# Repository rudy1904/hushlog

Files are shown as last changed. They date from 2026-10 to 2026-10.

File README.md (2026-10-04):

# Hushlog

A 4-channel, 24-bit data logger for small, slow signals — thermocouples, strain gauges, photodiodes, RTDs.

Most DIY loggers read tiny voltages with the microcontroller's built-in ADC, which is fine until the signal is small, at which point it's mostly noise. Hushlog uses a real 24-bit precision ADC (the TI ADS1220) with 4 input channels, read by a bare RP2040, logged to a microSD card, with a small OLED for live readings — all on a custom 2-layer board in a 3D-printed enclosure.

The thing I actually care about is keeping it **quiet**: a separate low-noise supply for the analog side, RC filtering on every input, and a layout that keeps the digital switching noise away from the ADC. Once it's built I'll short the inputs, measure the noise floor, and compare it to the datasheet — that number goes in this repo, good or bad.

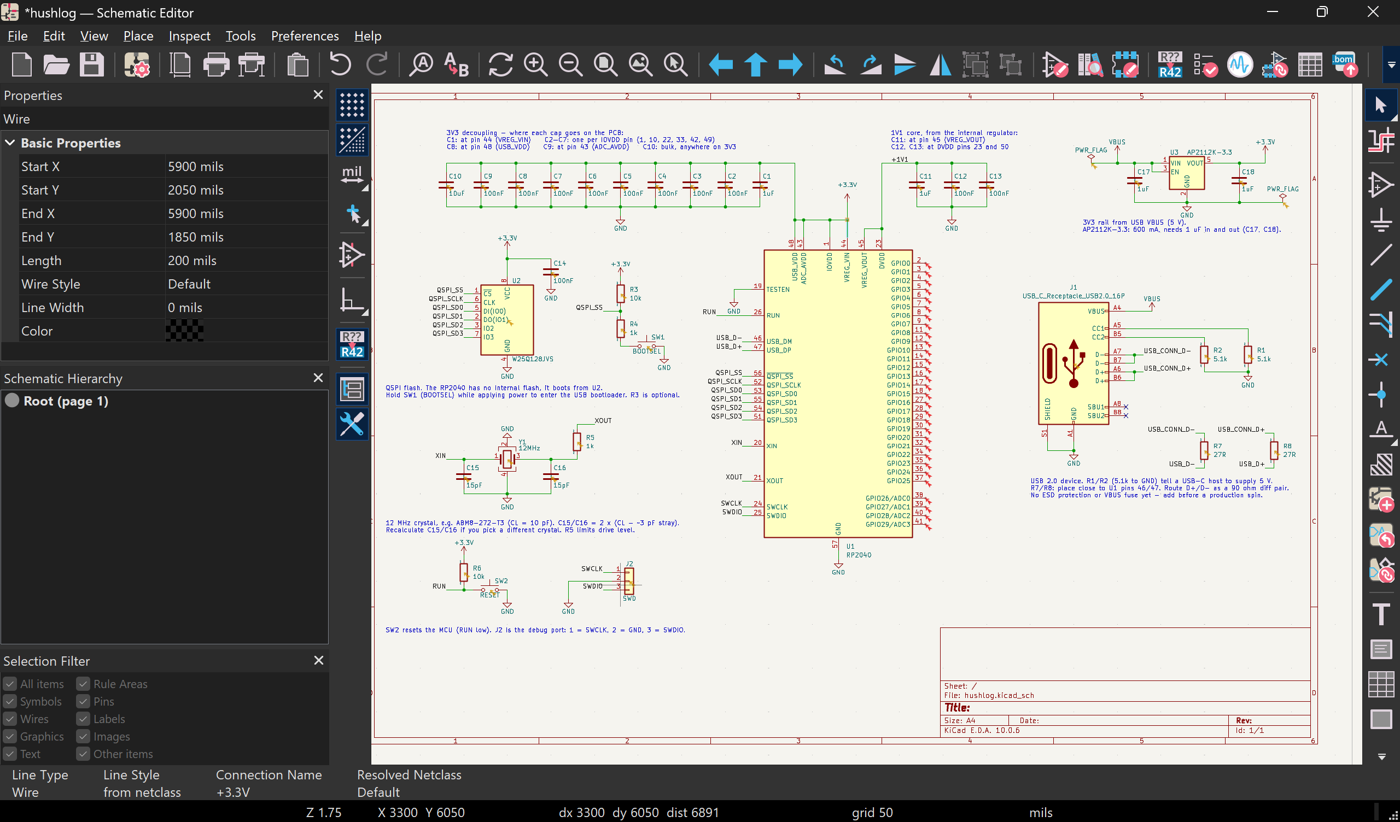
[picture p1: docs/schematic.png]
RP2040 core schematic


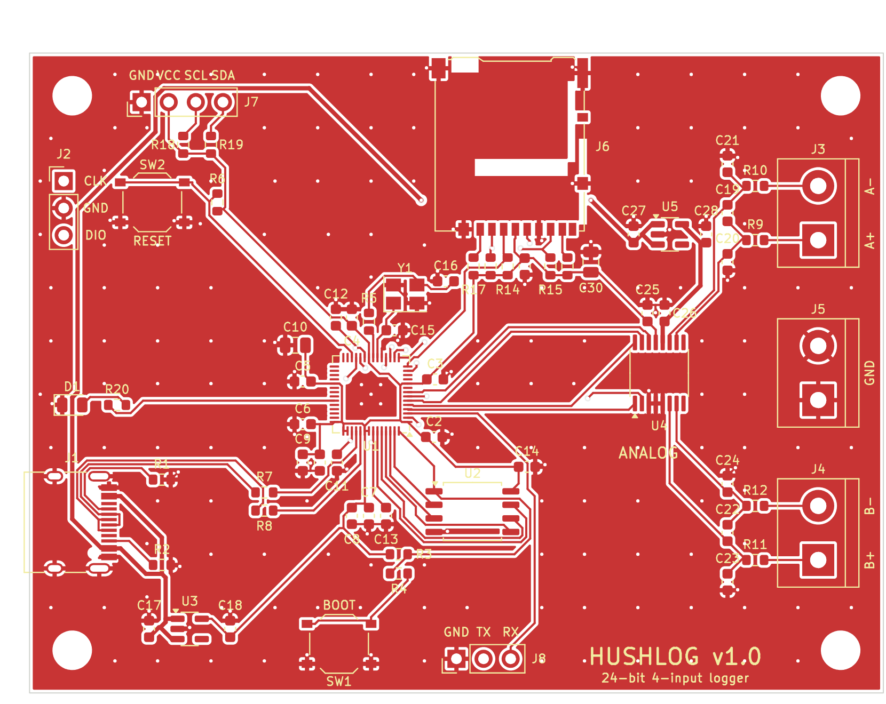
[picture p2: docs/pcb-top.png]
PCB, top copper and silkscreen


## Status

Design in progress for the Hack Club Half Life warm-up (Tier 2).

- [x] RP2040 core schematic — MCU, external QSPI flash, 12 MHz crystal, USB-C + LDO power, BOOTSEL/RESET, SWD. Power rails verified (VREG_VIN confirmed on +3.3V).
- [x] ADS1220 analog front end — two differential channels, computed input filters, SPI on hardware SPI0, separate low-noise LDO (AVDD isolated from digital rail, verified)
- [x] microSD (SPI1), OLED header (I2C1), screw terminals, status LED, UART header
- [x] PCB layout — 80 × 60 mm, 2 layers, analog/digital split, ground pour on both sides. Passes DRC with 0 errors and 0 unrouted nets in KiCad 7's DRC engine; still to be re-checked in KiCad 10 before ordering.
- [ ] Enclosure (3D-printed)
- [ ] Firmware (RP2040 + ADS1220 + SD logging)

## Design choices

- **Bare RP2040, not a Pico module** — designing the MCU circuit from scratch (reference design followed pin-for-pin so it boots first try).
- **External QSPI flash (W25Q128)** — the RP2040 has no internal flash.
- **Separate analog supply** — the ADC gets its own low-noise LDO so RP2040 switching noise doesn't couple into the measurement.
- **2-layer board** — kept deliberately simple for a first build; no need for 4 layers at these speeds.

## PCB

- 80 × 60 mm, 2 layers, four M3 mounting holes. Minimum track and gap 0.2 / 0.15 mm, vias 0.6 / 0.3 mm.
- Digital on the left (RP2040, flash, USB-C, microSD, OLED header), analog on the right (ADS1220, input filters, screw terminals, analog LDO).
- The bottom layer under the analog section is unbroken ground: a rule area forbids bottom-layer tracks there, so nothing can cut the plane under the ADC or the input filters.
- The 5 V feed for the analog LDO runs around the board edge and passes under the microSD socket, where no signal crosses the gap it leaves in the plane. It never enters the input-filter area.
- Input pairs: J3 = IN_A (pin 1 AIN1, pin 2 AIN0), J4 = IN_B (pin 1 AIN3, pin 2 AIN2), J5 = ground. MUX settings 0110 and 0111 make pin 1 the positive input.
- Fabrication files are in `fab/` (Gerbers, drill, placement, parts list).

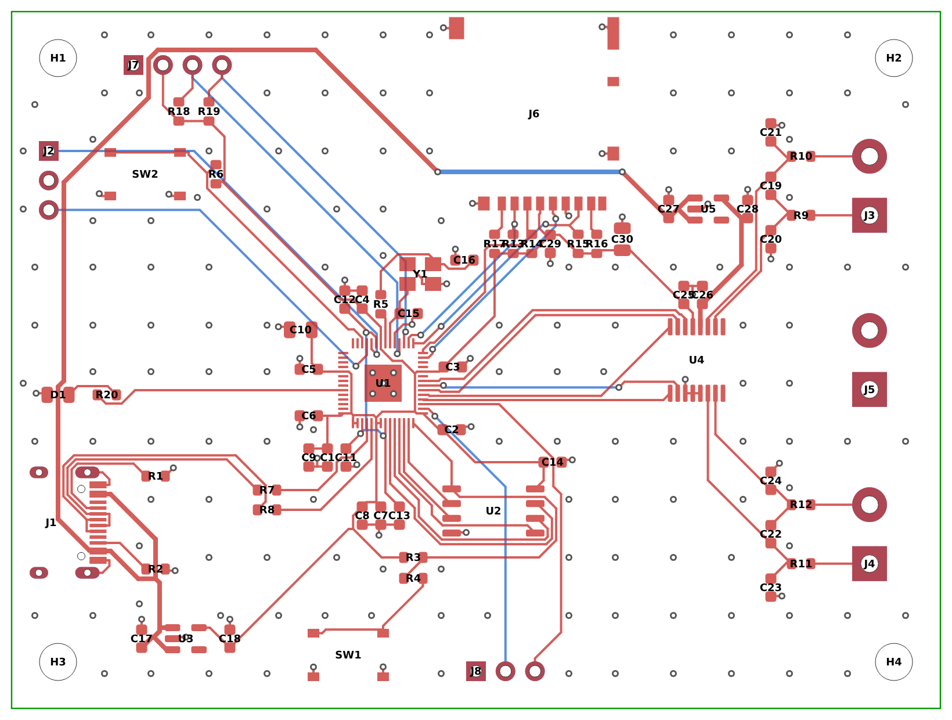
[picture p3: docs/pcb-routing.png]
PCB routing, both layers


## Hardware

- `hardware/` — KiCad 10 project (schematic + PCB)
- `docs/` — schematic render, board images, noise-floor results
- `cad/` — enclosure files
- `firmware/` — RP2040 firmware

## Parts (headline)

| Part | Role |
|---|---|
| RP2040 | microcontroller |
| W25Q128 | QSPI boot flash |
| ADS1220 | 24-bit ADC (4 ch) |
| AP2112K-3.3 | 3.3V LDO (digital) |
| TPS7A20 | low-noise LDO (analog) |
| SSD1306 0.96" | OLED display |

Full bill of materials in `BOM.md` (auto-synced from the Half Life project).

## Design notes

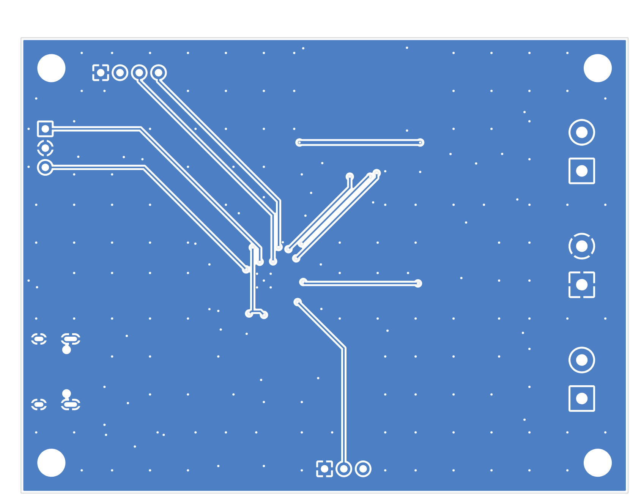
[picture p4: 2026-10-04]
docs/pcb-bottom.png

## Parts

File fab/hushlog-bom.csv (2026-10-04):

References | Qty | Value | Footprint | Part | Manufacturer | LCSC (unverified) | Unit price | Notes
C1 C11 C17 C18 C27 C28 | 6 | 1uF | C_0603_1608Metric | 1uF 0603 capacitor |  |  |  | X7R, 10 V or more (C17/C27 sit on 5 V VBUS)
C2 C3 C4 C5 C6 C7 C8 C9 C12 C13 C14 C19 C22 C25 C26 C29 | 16 | 100nF | C_0603_1608Metric | 100nF 0603 capacitor |  |  |  | X7R; C19/C22 (across the input pairs) are better as C0G/NP0 or film if the budget allows
C10 C30 | 2 | 10uF | C_0805_2012Metric | 10uF 0805 capacitor |  |  |  | X5R/X7R, 10 V or more
C15 C16 | 2 | 15pF | C_0603_1608Metric | 15pF 0603 capacitor |  |  |  | crystal load: C0G/NP0
C20 C21 C23 C24 | 4 | 10nF | C_0603_1608Metric | 10nF 0603 capacitor |  |  |  | input common-mode filter: use C0G/NP0
D1 | 1 | LED | LED_0805_2012Metric | 0805 green LED
J1 | 1 | USB_C_Receptacle_USB2.0_16P | USB_C_Receptacle_HRO_TYPE-C-31-M-12 | TYPE-C-31-M-12 | Korean Hroparts | C165948 |  | 16-pin USB 2.0 receptacle
J2 | 1 | SWD | PinHeader_1x03_P2.54mm_Vertical | 1x3 2.54 mm header
J3 | 1 | IN_A | TerminalBlock_bornier-2_P5.08mm | 2-way 5.08 mm screw terminal
J4 | 1 | IN_B | TerminalBlock_bornier-2_P5.08mm | 2-way 5.08 mm screw terminal
J5 | 1 | GND | TerminalBlock_bornier-2_P5.08mm | 2-way 5.08 mm screw terminal
J6 | 1 | Micro_SD_Card | microSD_HC_Hirose_DM3AT-SF-PEJM5 | DM3AT-SF-PEJM5 | Hirose | C114218 |  | push-push; footprint is for this exact part
J7 | 1 | OLED | PinHeader_1x04_P2.54mm_Vertical | 1x4 2.54 mm header (or socket) |  |  |  | for a 0.96 in SSD1306 I2C module, pin order GND-VCC-SCL-SDA
J8 | 1 | UART | PinHeader_1x03_P2.54mm_Vertical | 1x3 2.54 mm header
R1 R2 | 2 | 5.1k | R_0603_1608Metric | 5.1k 0603 resistor 1%
R3 R6 R13 R14 R15 R16 R17 | 7 | 10k | R_0603_1608Metric | 10k 0603 resistor 1%
R4 R5 R9 R10 R11 R12 R20 | 7 | 1k | R_0603_1608Metric | 1k 0603 resistor 1%
R7 R8 | 2 | 27R | R_0603_1608Metric | 27R 0603 resistor 1%
R18 R19 | 2 | 4.7k | R_0603_1608Metric | 4.7k 0603 resistor 1%
SW1 | 1 | BOOTSEL | SW_Push_1P1T_XKB_TS-1187A | TS-1187A-B-A-B | XKB | C318884 |  | tactile switch 5.1x5.1 mm
SW2 | 1 | RESET | SW_Push_1P1T_XKB_TS-1187A | TS-1187A-B-A-B | XKB | C318884 |  | tactile switch 5.1x5.1 mm
U1 | 1 | RP2040 | QFN-56-1EP_7x7mm_P0.4mm_EP3.2x3.2mm | RP2040 | Raspberry Pi | C2040
U2 | 1 | W25Q128JVS | SOIC-8_5.3x5.3mm_P1.27mm | W25Q128JVSIQ | Winbond | C97521 |  | SOIC-8 208 mil
U3 | 1 | AP2112K-3.3 | SOT-23-5 | AP2112K-3.3TRG1 | Diodes Inc. | C51118
U4 | 1 | ADS1220IPW | TSSOP-16_4.4x5mm_P0.65mm | ADS1220IPWR | Texas Instruments |  |  | TSSOP-16
U5 | 1 | TPS7A2033PDBV | SOT-23-5 | TPS7A2033PDBVR | Texas Instruments |  |  | 3.3 V low-noise LDO
Y1 | 1 | 12MHz | Crystal_SMD_Abracon_ABM8G-4Pin_3.2x2.5mm | ABM8-272-T3 | Abracon |  |  | 12 MHz, CL 10 pF, 3.2x2.5 mm; recalculate C15/C16 for any other crystal
(not on the board) | 1 | OLED module |  | 0.96 in SSD1306 I2C module |  |  |  | check its pin order against J7
(not on the board) | 1 | PCB |  | 80 x 60 mm, 2 layers, 1.6 mm

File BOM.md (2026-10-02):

# Hushlog — bill of materials

<!-- Generated by Half Life from project cmupluruv071a01s14q1s25uq. Edits here are overwritten on the next sync. -->
<!-- Generated: 1970-01-01T00:00:00.000Z -->

> [!NOTE]
> This parts list is mirrored from [Half Life](https://halflife.hackclub.com). Editing it here will not change the platform's copy, and the next sync overwrites this file.

| Week | Tier | Parts funding |
| --- | --- | --- |
| Warm-up | Tier 2 | $65.00 |

_No parts listed yet._

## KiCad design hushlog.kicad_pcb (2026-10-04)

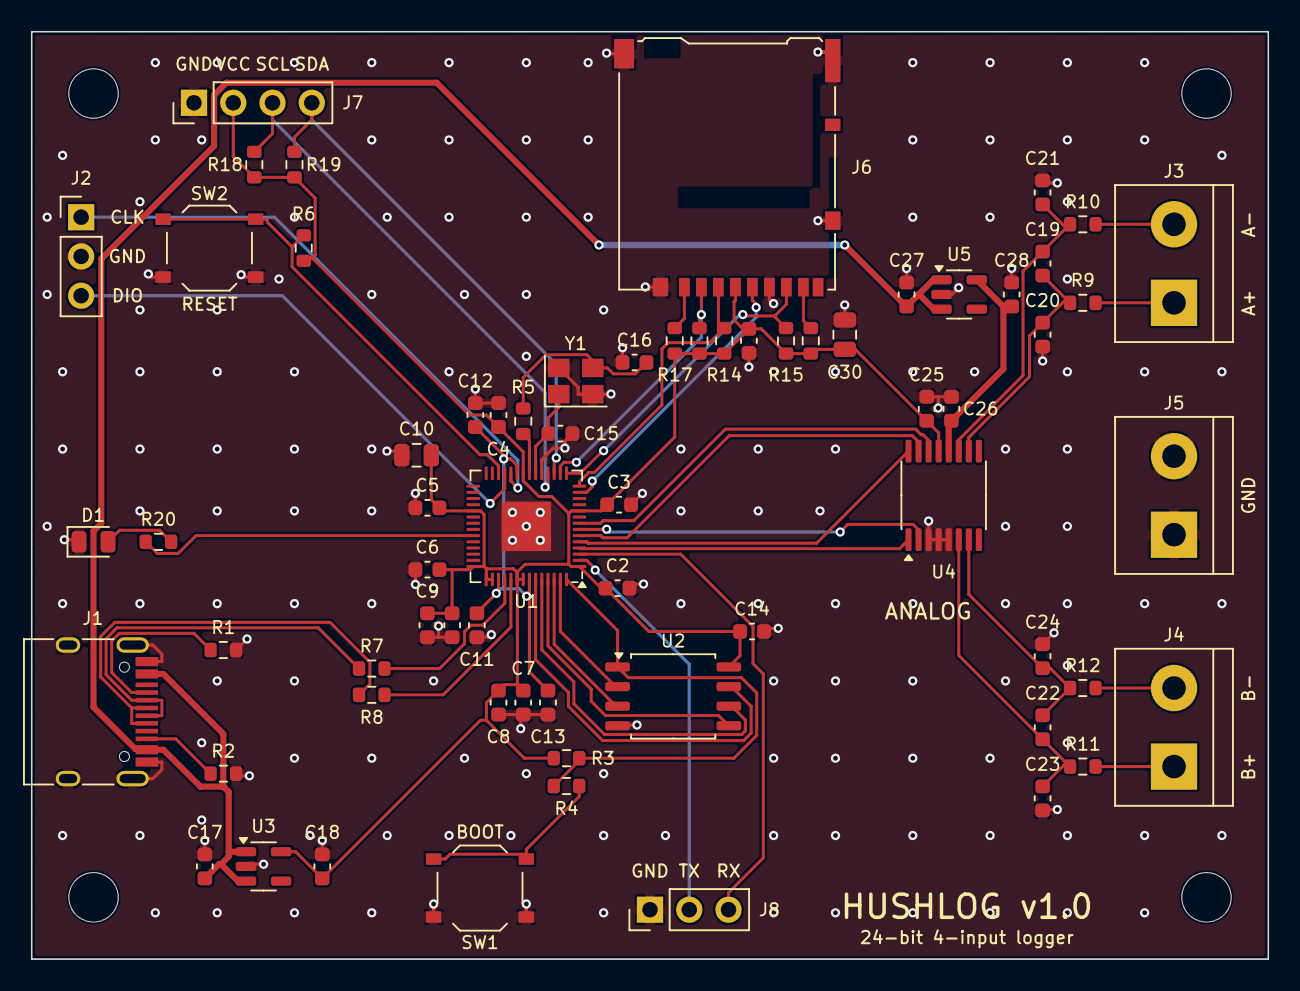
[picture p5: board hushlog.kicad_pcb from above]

Board: 2 copper layers, 80.0 x 60.0 mm, 71 parts (0 on the bottom side), 49 nets.

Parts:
C1, C11, C17, C18, C27, C28: 1uF; C_0603_1608Metric
C2, C3, C4, C5, C6, C7, C8, C9, C12, C13, C14, C19, C22, C25, C26, C29: 100nF; C_0603_1608Metric
C10, C30: 10uF; C_0805_2012Metric
C15, C16: 15pF; C_0603_1608Metric
C20, C21, C23, C24: 10nF; C_0603_1608Metric
D1: LED; LED_0805_2012Metric
H1, H2, H3, H4: M3; MountingHole_3.2mm_M3
J1: USB_C_Receptacle_USB2.0_16P; USB_C_Receptacle_HRO_TYPE-C-31-M-12
J2: SWD; PinHeader_1x03_P2.54mm_Vertical
J3: IN_A; TerminalBlock_bornier-2_P5.08mm
J4: IN_B; TerminalBlock_bornier-2_P5.08mm
J5: GND; TerminalBlock_bornier-2_P5.08mm
J6: Micro_SD_Card; microSD_HC_Hirose_DM3AT-SF-PEJM5
J7: OLED; PinHeader_1x04_P2.54mm_Vertical
J8: UART; PinHeader_1x03_P2.54mm_Vertical
R1, R2: 5.1k; R_0603_1608Metric
R3, R6, R13, R14, R15, R16, R17: 10k; R_0603_1608Metric
R4, R5, R9, R10, R11, R12, R20: 1k; R_0603_1608Metric
R7, R8: 27R; R_0603_1608Metric
R18, R19: 4.7k; R_0603_1608Metric
SW1: BOOTSEL; SW_Push_1P1T_XKB_TS-1187A
SW2: RESET; SW_Push_1P1T_XKB_TS-1187A
U1: RP2040; QFN-56-1EP_7x7mm_P0.4mm_EP3.2x3.2mm
U2: W25Q128JVS; SOIC-8_5.3x5.3mm_P1.27mm
U3: AP2112K-3.3; SOT-23-5
U4: ADS1220IPW; TSSOP-16_4.4x5mm_P0.65mm
U5: TPS7A2033PDBV; SOT-23-5
Y1: 12MHz; Crystal_SMD_Abracon_ABM8G-4Pin_3.2x2.5mm

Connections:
+3.3V: C1.1, C2.1, C3.1, C4.1, C5.1, C6.1, C7.1, C8.1, C9.1, C10.1, C14.1, C18.1, C25.1, C29.1, C30.1, J6.4 (VDD), J7.2, R3.1, R6.1, R13.1, R14.1, R15.1, R16.1, R17.1, R18.1, R19.1, U1.1 (IOVDD), U1.10 (IOVDD), U1.22 (IOVDD), U1.33 (IOVDD), U1.42 (IOVDD), U1.43 (ADC_AVDD), U1.44 (VREG_VIN), U1.48 (USB_VDD), U1.49 (IOVDD), U2.8 (VCC), U3.5 (VOUT), U4.13 (DVDD)
+3.3VA: C26.1, C28.1, U4.12 (AVDD), U5.5 (OUT)
/+1V1: C11.1, C12.1, C13.1, U1.23 (DVDD), U1.45 (VREG_VOUT), U1.50 (DVDD)
/ADC_CS: U1.7 (GPIO5), U4.2 (~CS)
/ADC_DRDY: U1.8 (GPIO6), U4.14 (~DRDY)
/ADC_MISO: U1.6 (GPIO4), U4.15 (DOUT/~DRDY)
/ADC_MOSI: U1.5 (GPIO3), U4.16 (DIN)
/ADC_SCLK: U1.4 (GPIO2), U4.1 (SCLK)
/AIN0: C19.2, C21.1, R10.2, U4.11 (AIN0/REFP1)
/AIN1: C19.1, C20.2, R9.2, U4.10 (AIN1)
/AIN2: C22.2, C24.1, R12.2, U4.7 (AIN2)
/AIN3: C22.1, C23.2, R11.2, U4.6 (AIN3/REFN1)
/OLED_SCL: J7.3, R18.2, U1.18 (GPIO15)
/OLED_SDA: J7.4, R19.2, U1.17 (GPIO14)
/QSPI_SCLK: U1.52 (QSPI_SCLK), U2.6 (CLK)
/QSPI_SD0: U1.53 (QSPI_SD0), U2.5 (DI/IO_{0})
/QSPI_SD1: U1.55 (QSPI_SD1), U2.2 (DO/IO_{1})
/QSPI_SD2: U1.54 (QSPI_SD2), U2.3 (~WP/IO_{2})
/QSPI_SD3: U1.51 (QSPI_SD3), U2.7 (~HOLD/~RESET/IO_{3})
/QSPI_SS: R3.2, R4.1, U1.56 (~QSPI_SS), U2.1 (~CS)
/RUN: R6.2, SW2.1, U1.26 (RUN)
/SD_CS: J6.2 (DAT3/CD), R13.2, U1.16 (GPIO13)
/SD_DAT1: J6.8 (DAT1), R16.2
/SD_DAT2: J6.1 (DAT2), R17.2
/SD_MISO: J6.7 (DAT0), R15.2, U1.15 (GPIO12)
/SD_MOSI: J6.3 (CMD), R14.2, U1.14 (GPIO11)
/SD_SCLK: J6.5 (CLK), U1.13 (GPIO10)
/SWCLK: J2.1, U1.24 (SWCLK)
/SWDIO: J2.3, U1.25 (SWDIO)
/UART_RX: J8.3, U1.3 (GPIO1)
/UART_TX: J8.2, U1.2 (GPIO0)
/USB_CONN_D+: J1.A6 (D+), J1.B6 (D+), R8.1
/USB_CONN_D-: J1.A7 (D-), J1.B7 (D-), R7.1
/USB_D+: R8.2, U1.47 (USB_DP)
/USB_D-: R7.2, U1.46 (USB_DM)
/XIN: C15.1, U1.20 (XIN), Y1.1
/XOUT: R5.1, U1.21 (XOUT)
GND: C1.2, C2.2, C3.2, C4.2, C5.2, C6.2, C7.2, C8.2, C9.2, C10.2, C11.2, C12.2, C13.2, C14.2, C15.2, C16.2, C17.2, C18.2, C20.1, C21.2, C23.1, C24.2, C25.2, C26.2, C27.2, C28.2, C29.2, C30.2, D1.1 (K), J1.A1 (GND), J1.A12 (GND), J1.B1 (GND), J1.B12 (GND), J1.SH (SHIELD), J2.2, J5.1, J5.2, J6.6 (VSS), J6.SH (SHIELD), J7.1, J8.1, R1.2, R2.2, SW1.2, SW2.2, U1.19 (TESTEN), U1.57 (GND), U2.4 (GND), U3.2 (GND), U4.3 (CLK), U4.4 (DGND), U4.5 (AVSS), U5.2 (GND), Y1.2 (G), Y1.4 (G)
unnamed: C16.1, R5.2, Y1.3
unnamed: D1.2 (A), R20.2
unnamed: J1.A5 (CC1), R1.1
unnamed: J1.B5 (CC2), R2.1
unnamed: J3.1, R9.1
unnamed: J3.2, R10.1
unnamed: J4.1, R11.1
unnamed: J4.2, R12.1
unnamed: R4.2, SW1.1
unnamed: R20.1, U1.37 (GPIO25)
VBUS: C17.1, C27.1, J1.A4 (VBUS), J1.A9 (VBUS), J1.B4 (VBUS), J1.B9 (VBUS), U3.1 (VIN), U3.3 (EN), U5.1 (IN), U5.3 (EN)

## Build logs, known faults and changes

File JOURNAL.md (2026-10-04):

# Hushlog — devlog

<!-- Generated by Half Life from project cmupluruv071a01s14q1s25uq. Edits here are overwritten on the next sync. -->
<!-- Generated: 2026-10-04T11:35:24.640Z -->

> [!NOTE]
> This devlog is mirrored from [Half Life](https://halflife.hackclub.com). Editing it here will not change the platform's copy, and the next sync overwrites this file.

> Hushlog is basically a little box that measures really tiny voltages and saves them to an SD card. Most DIY data loggers just use the microcontroller's built-in ADC, which is fine until you try to measure something small like a thermocouple and it's all noise. So I'm using an actual 24-bit ADC (the ADS1220) with 4 input channels, plus a small OLED so you can see the readings live. I'm designing the whole board myself, including the RP2040 part from scratch instead of just slapping a Pico on it. The main thing I'm going for is making it quiet: separate power for the analog side, filters on every input, and keeping all the noisy digital stuff away from the ADC. Once it's built I'm going to short the inputs, measure the noise floor, and see how close I can get to the datasheet. Whatever number I get goes in the repo, even if it's bad lol

| Week | Tier | Hours logged | Entries |
| --- | --- | --- | --- |
| Warm-up | Tier 2 | 17.5h | 4 |

## Contents

1. [2026-10-02 — RP2040 core done :  5 hours, and it should boot](#2026-10-02-rp2040-core-done-5-hours-and-it-should-boot)
2. [2026-10-02 — Analog front end : the ADS1220, the whole point of this thing](#2026-10-02-analog-front-end-the-ads1220-the-whole-point-of-t)
3. [2026-10-03 — SD card + OLED + status I/O :  schematic is done, ERC clean](#2026-10-03-sd-card-oled-status-io-schematic-is-done-erc-clea)
4. [2026-10-04 — PCB layout : the board is real now](#2026-10-04-pcb-layout-the-board-is-real-now)

## Design

### 2026-10-02 — RP2040 core done :  5 hours, and it should boot

**5h**

RP2040 core done :  5 hours, and it should boot

Spent this whole sitting (~5h) drawing the brain of Hushlog: the RP2040 plus everything it needs to actually power up and run, before any of the logging hardware goes on. The RP2040 is fiddly because it doesn't run off a single voltage. It has a regulator built in, so you feed 3.3V into VREG_VIN, it puts out 1.1V at VREG_VOUT, and you have to loop that 1.1V back into DVDD yourself to power the core. Getting that wrong kills the chip, so that's where I was most careful.

Started by placing the chip and sorting the power pins. IOVDD, USB_VDD and ADC_AVDD all go to the 3.3V rail; VREG_VOUT ties back to DVDD as its own 1V1 rail.



Built out the full decoupling: a 100nF at every supply pin, a 10µF bulk cap on 3.3V, and 1µF + 100nF on the 1V1 core rail. Then the rest of the core — the W25Q128 QSPI flash (the RP2040 has no internal flash, it boots off this), the 12 MHz crystal with 15pF load caps, the USB-C connector with 5.1k CC resistors and 27Ω series resistors on the data lines, an AP2112K LDO making the 3.3V from USB 5V, and the BOOTSEL/RESET buttons plus an SWD header.



Hit one snag with the flash: the SOIC-8 footprint I first assigned wasn't in my library, and ERC threw "footprint not found." Fixed it by opening the footprint chooser, clearing the filters (it was filtering for a footprint that didn't exist, so the list came up empty), and picking the standard Package_SO:SOIC-8_3.9x4.9mm_P1.27mm.

When I ran "Update Symbols from Library" it told me there was nothing to rescue, which is what you want — means my symbols are clean.



The one check I really wanted to nail: I clicked the wire on pin 44 (VREG_VIN) to confirm it actually lands on +3.3V and isn't accidentally tied to the 1.1V rail. KiCad confirmed the net resolves to +3.3V.



Ran ERC to close out. 30 errors left, every one a GPIO "pin not connected." Those aren't bugs — they're my to-do list, one per pin waiting on a peripheral. I'm deliberately leaving them erroring instead of hiding them with no-connect flags; they'll clear as I wire up the ADC, SD card, OLED and screw terminals. The 34 warnings are all cosmetic library-version mismatches and don't affect the board.



### 2026-10-02 — Analog front end : the ADS1220, the whole point of this thing

**3h**

Analog front end : the ADS1220, the whole point of this thing

This session (~3h) I built the part Hushlog actually exists for: the 24-bit ADC that reads the small signals the RP2040's own ADC can't. Added the ADS1220 to the same sheet as the core, next to the MCU.

Wired it as two differential pairs rather than four single-ended inputs. That was a deliberate choice: Hushlog is meant for thermocouples, strain gauges and RTDs, and those are tiny differential signals that need the PGA at high gain. Single-ended would've capped the gain low and made the board worse at exactly the thing it's for. Costs a handful more passives, worth it. Each pair can still be used as two single-ended channels if I want, so I didn't lose flexibility.



The input filtering is where the real analog thinking went. Each pair gets 1k series resistors on both legs, 100nF from each leg to GND, and a 10nF cap across the pair. I worked out the corner frequencies: differential rolls off around 760 Hz, common-mode around 16 kHz. That band-limits the inputs to slow signals, which is exactly right for thermocouples and RTDs, and it's the antialiasing filter the datasheet asks for. Reference and clock are both internal (CLK tied to GND picks the internal oscillator, REFP0/REFN0 unused selects the internal 2.048V reference), which keeps the parts count down and is the most robust setup for a first board.

For SPI I used the RP2040's hardware SPI0 block: GPIO2 SCLK, GPIO3 MOSI, GPIO4 MISO, GPIO5 CS, GPIO6 for DRDY. Mode 1, matching the ADS1220. Connected them with net labels instead of dragging wires across the sheet.



The bit I'm most pleased with is the supply. The ADS1220's analog side (AVDD) runs off its own low-noise LDO, a TPS7A2033, fed straight from USB VBUS so the noisy digital 3.3V rail never touches it. I checked this actually worked rather than assuming: clicked the AVDD wire and KiCad confirmed it's on the +3.3VA net, separate from +3.3V. Also confirmed the LDO's EN pin is tied to its input so the regulator is actually on, not floating. 1µF in and out as the datasheet wants.



Ran ERC. Error count dropped from 30 to 25 — the five that cleared are the SPI GPIOs now in use. The remaining 25 are still the unconnected GPIOs waiting for the SD card and OLED, left erroring on purpose as the to-do list.

tldr: Built and verified the ADS1220 analog front end in ~3h : two differential channels, computed input filters, SPI on the RP2040's hardware block, and a separate low-noise analog supply confirmed isolated from the digital rail. Next: microSD socket and OLED header, then PCB layout.

### 2026-10-03 — SD card + OLED + status I/O :  schematic is done, ERC clean

**2.5h**

SD card + OLED + status I/O :  schematic is done, ERC clean

This session (~2.5h) finished the last of the electrical design: storage, display, and some debug I/O. Everything Hushlog needs is now on the sheet.

Added the microSD socket on the RP2040's second hardware SPI bus (SPI1), deliberately separate from the ADC's SPI0 so the two never collide. Put 10k pull-ups on the SPI lines (standard for SD-over-SPI reliability) and a 10µF bulk cap at the card's supply, since SD cards pull current spikes during writes.



Added the OLED as a 4-pin I2C header rather than a bare SSD1306 panel, which keeps the layout simpler and lets me use a cheap module. Two 4.7k pull-ups on SDA/SCL. One thing I flagged for myself: OLED modules vary in pin order (GND/VCC/SCL/SDA vs VCC/GND/SDA/SCL), so I need to confirm the order against the exact module I buy before layout, or it's a rework.

Then I dealt with the spare GPIOs. Instead of just no-connecting all of them, I added a status LED on GPIO25 (so the board can show "recording" or "SD error" without the OLED) and broke GPIO0/GPIO1 out to a UART header for serial debugging. That UART is going to matter in build week, the OLED can only show a line, but printf-over-UART gives a full log when the firmware misbehaves. The remaining 16 unused GPIOs got proper no-connect flags, which is the honest way to say "checked, deliberately spare" rather than leaving them erroring.



Ran ERC and cleared it to 0 errors. Down from the 30 I started the ADC session with. The 2 warnings left are just symbol-library version mismatches on the LED and the analog LDO, cosmetic, don't affect the netlist.



Firmware note to self: don't write to the SD card or refresh the OLED while the ADC is mid-conversion, or those switching events show up in the noise floor.

tldr: SD (SPI1), OLED (I2C), status LED and UART debug header all added; spare GPIOs properly no-connected; ERC clean at 0 errors. The whole electrical design is finished. Next: assign footprints, then PCB layout.

### 2026-10-04 — PCB layout : the board is real now

**7h**

PCB layout : the board is real now

This was the big session (~6.5h): took the finished schematic and turned it into an actual 2-layer board, placed, routed, ground-poured, and passing DRC. 80×60mm, 67 parts, four M3 mounting holes.

The placement was the important decision, and it's built entirely around keeping the measurement quiet. The board is split into two zones: everything digital (RP2040, flash, crystal, USB-C, SD card, OLED, UART, status LED) on the left, and everything analog (the ADS1220, its own low-noise LDO, and all four input filters) on the right, with the screw terminals out on the right edge so sensor wires come straight in without crossing the digital side.





I was upfront about the method: placement and routing were done with an automated tools (Freerouting plus scripting), and a bit of hand-routing where the tool was going wrong (ps, took mmore time than I thought it would). and then  what I set by hand are the constraints that actually matter for this board: no track runs on the bottom layer under the ADC, its filters, or the terminals, so the ground plane stays solid underneath the analog section; and the 5V feed to the analog LDO is routed around the board edge rather than through the sensitive input area. Decoupling caps are kept right at their chip pins.



There's a ground pour on both layers, kept unbroken under the ADS1220. One schematic tweak fell out of layout: the terminal pin assignment was flipped (pin 1 → AIN1/AIN3, pin 2 → AIN0/AIN2) to avoid putting vias on the analog inputs; firmware handles it with the right MUX setting.

Checked it properly in KiCad 10: ran Update-PCB-from-Schematic (0 errors), refilled zones, and ran DRC. 0 errors, 0 unrouted nets. The 66 warnings are all cosmetic, footprint library-version mismatches and the USB connector's silkscreen clipping the board edge, none affect the board.









tldr: Full 2-layer PCB laid out, auto-routed with hand-set analog constraints (solid ground under the ADC, isolated analog supply), ground-poured, DRC clean at 0 errors. The design is done. Next: BOM and submission.

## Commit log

2026-10-02 Add RP2040 core schematic
    [hushlog.kicad_pcb, hushlog.kicad_sch]
2026-10-02 Add README with schematic image
    [hushlog.kicad_sch]
2026-10-02 Add ADS1220 analog front end
    [hushlog.kicad_sch]
2026-10-03 Add SD card, OLED, status LED and UART header; ERC clean
2026-10-04 PCB layout done
    [hushlog-B_Cu.gbl, hushlog-B_Mask.gbs, hushlog-B_Paste.gbp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]
2026-10-22 Update README with schematic and PCB routing images
    Added schematic and PCB routing images to README.
